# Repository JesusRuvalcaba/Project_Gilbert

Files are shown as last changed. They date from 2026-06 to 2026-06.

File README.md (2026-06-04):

# SHPE - Project Gilbert - Team 2



To control RC Car with cellphone:

1) search for wifi SSID RC-Car
2) enter password: 12345678
3) open up the link below

http://192.168.4.1/

## Project Description

Project Gilbert is a multidisciplinary RC car engineering project developed through SHPE to provide students with practical experience in mechanical, electrical, and manufacturing system design. The project focused on the development and integration of key vehicle subsystems including the rack and pinion steering mechanism, rear suspension system, circuit design, and overall system assembly. Team members collaborated to design, manufacture, assemble, and test a functional RC vehicle while applying engineering concepts learned in coursework to a real-world project environment.

The project also served as a mentorship-driven learning experience where upperclassmen and project leads guided lowerclassmen students throughout the design and development process. Through subsystem integration, design reviews, troubleshooting, and collaborative problem solving, members gained hands-on experience in engineering workflow, manufacturing processes, project coordination, and technical communication.

# Contributors

## Project Leadership Team

This team was responsible for overseeing system integration, project coordination, manufacturing operations, and final project execution.

| Name | Major / Position | Year | Role / Responsibility |
| --- | --- | --- | --- |
| Crystal Duran | SHPE Internal Vice President  | Junior | Project Manager |
| Jesus Ruvalcaba | Electrical Engineering | Senior | Systems and Electrical Operations Lead |
| Gabriel Contreras | Manufacturing Engineering | Sophomore | Manufacturing Operations Lead |
| Pedro Perez | Electromechanical Engineering | Senior | Electromechanical Systems Lead |

## Project Members

These members contributed to the mechanical, electrical, and structural development of the RC car project subsystems.

| Name | Major / Position | Year | Role / Responsibility  |
| --- | --- | --- | --- |
| Josue Garcia | Industrial Engineering | Junior | Rack and Pinion System |
| Andy Petrosyan | Electrical Engineering | Junior | Circuit Design |
| Louis Valdez | Business | Freshman  | Rear Suspension |
| Alison Lobato | Mechanical Engineering | Junior | Rear Suspension |
| David Calvillo | Computer Engineering | Junior | Circuit Assembly |
| Jesus Ruvalcaba | Electrical Engineering | Senior | Electrical Operations  |
| Gabriel Contreras | Manufacturing Engineering | Sophomore | Manufacturing Engr |
| Pedro Perez | Electromechanical Engr | Senior | Electromechanical Engr |

# Cost Breakdown

| Part Name | Quantity | Cost | Link |
| --- | ---: | -----: | --- |
| HiLetgo ESP32 Development Board (3 Pack) | 1 | $17.99 | [ESP32](https://www.amazon.com/Hosyond-Development-Bluetooth-Microcontroller-ESP-WROOM-32/dp/B0F1MS5S8R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) |
| DC Brushed Motor | 2 | $13.78 | [DC Gear Motor](https://www.amazon.com/AUTOTOOLHOME-Torque-Traxxas-Wheels-Electric/dp/B01M58POHF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) |
| L298N Dual H-Bridge Motor Driver | 1 | $13.96 | [L298N Motor Driver](https://www.amazon.com/WWZMDiB-L298N-H-Bridge-Controller-Raspberry/dp/B0CR6BX5QL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) |
| SPST Switch | 1 | $6.39 | [Switch](https://www.amazon.com/DaierTek-Listed-Switches-Automotive-KCD1-5Pack/dp/B07S1MV462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) |
| OVONIC 3S Lipo Battery | 1 | $31.77 | [3S LiPo Battery](https://www.amazon.com/2200mAh-Connector-Airplane-Quadcopter-Helicopter/dp/B09H4KXMQN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) |
| Servo Motor | 1 | $6.99  | [SG90 Servo Motor](amazon.com/WWZMDiB-SG90-Control-Servos-Arduino/dp/B0BKPL2Y21/ref=sr_1_6?crid=1XDTNJYFWU4KS&dib=eyJ2IjoiMSJ9.wV3YRE0vrk5NgH4crAjzDEoYHpGjwiz1Dc3dH15isinuQetsXrt_fsj-g4PERVIjlcI2V5iI2CihxPryMwUoDp31VpTsu_B2qpzuIdXXhYxltGqyU-L95wtvq1BCL1d9exqFyQHK7Nt16iQFr-j1BTByevHCWSGFMXNCUYdxC99eTE45NW--ezeMFAPqfdqIHs2zPiukl7vhPzZloINiAMM8phPkUt_d6b19prHK0awdWFKd6Jh8KGxvOHuXSq5BsIDauRkilJLxKc08cH1Hz7eRctWm45x0yYG4icI7VzE.Q67aCZ9-nO-3GVM6RTWrR4g8cGWnOm49spEnjnQ61W4&dib_tag=se&keywords=servo+motor&qid=1780536184&sprefix=servo+motor%2Caps%2C256&sr=8-6) |
| Adjustable Buck Converter | 1 | $13.99 | [Buck Converter](https://www.amazon.com/Adjustable-Converter-1-25-36v-Efficiency-Regulator/dp/B079N9BFZC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) |
|  Electrical Total Cost (with ~10% tax headroom) | $115.36 |

# Design Review

During the design review, team members presented the current progress of the RC car project to the mentors and project leads, covering the mechanical, electrical, and manufacturing aspects of the system. Discussions included the rack and pinion steering implementation, rear suspension development, circuit design progress, and overall circuit assembly integration. Mentors and leads evaluated subsystem compatibility, reviewed design decisions, and provided technical feedback regarding manufacturability, system reliability, and project organization. The review also focused on identifying integration challenges, validating design approaches, and ensuring each subsystem was progressing according to project objectives and timelines. Action items and recommendations were documented to guide future development and system refinement.
  
https://docs.google.com/presentation/d/1H8Z8eRnMIN4K8d28Y-c5Z4X9QktE7rCTanJxe8Py7WY/edit?usp=sharing

[CDR Gilbert.pdf](https://github.com/user-attachments/files/27575757/CDR.Gilbert.pdf)

# Final Assembly Overview



## Chassis Sub Assembly


## Powertrain Suspension Sub Assembly


## Steering Suspension Sub Assembly


## Future Improvements

One of the main lessons learned from this project was that the drivetrain did not provide enough torque for the vehicle to perform as well as expected, especially when carrying additional load or driving over uneven surfaces. A future version of the design could improve this by using a rear-wheel-drive (RWD) differential system with a 10:1 gear ratio and a single brushless motor paired with an ESC. This setup would provide more torque, improve overall efficiency, and offer better driving performance than the current brushed motor configuration.

Another lesson learned was related to the L298N motor driver. During testing, the driver became noticeably hot when the motors stalled or were placed under heavy load. This occurred because the L298N is based on BJT transistor technology, which is less efficient and dissipates more power as heat compared to modern MOSFET-based motor controllers. Future designs would benefit from using a more efficient motor driver or ESC to reduce heat generation and improve overall system reliability.

Another improvement would be replacing the current phone-based Wi-Fi control system with ESP-NOW communication between two ESP32 modules. During testing, Wi-Fi control through a web page introduced connection delays and depended on a phone being connected to the vehicle's network. Using ESP-NOW would provide a more responsive and reliable control link, creating a driving experience that is closer to a traditional RC vehicle while simplifying operation for the user.

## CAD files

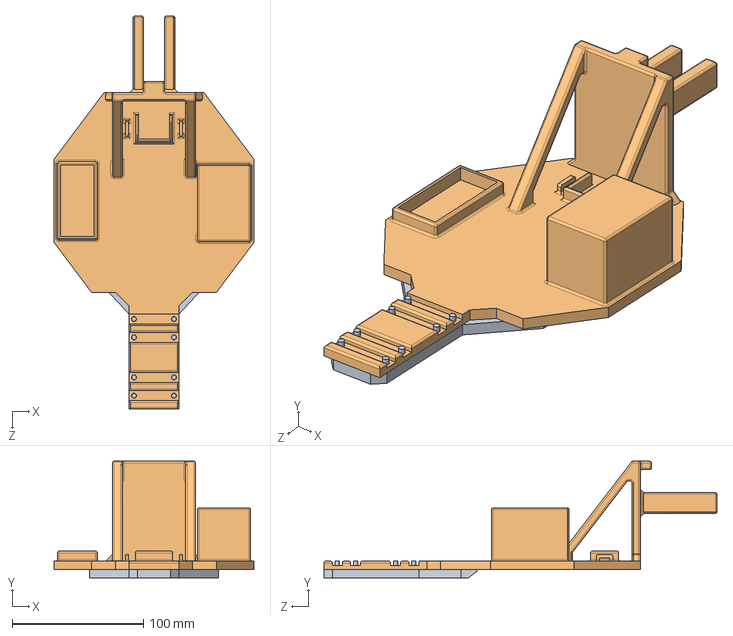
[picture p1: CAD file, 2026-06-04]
RC Project Github/Chassis Sub Assembly/Chassis Sub Assembly.SLDASM
152.4 x 88.9 x 299.7 mm
RC front chassis part
strength plate

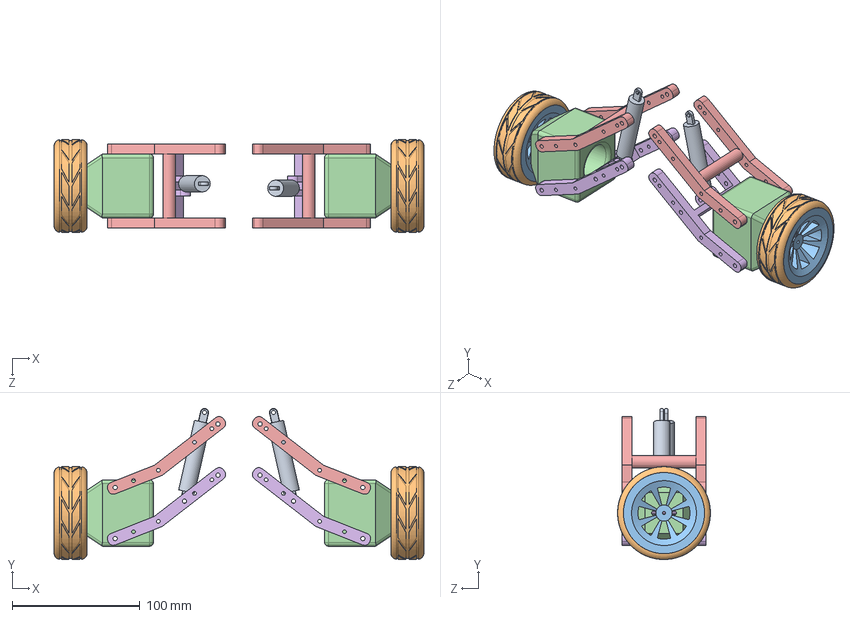
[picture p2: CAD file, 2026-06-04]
RC Project Github/Powertrain Suspension Sub Assembly/Powertrain Suspension Sub Assembly.SLDASM
289.6 x 118.2 x 72.7 mm
Lower Arm to Bracket x 2
Arm to Bracket x 2
Motor Bracket 2 x 2
RC drivetrain rims x 2
RC tire large x 2
RC rear shock x 2

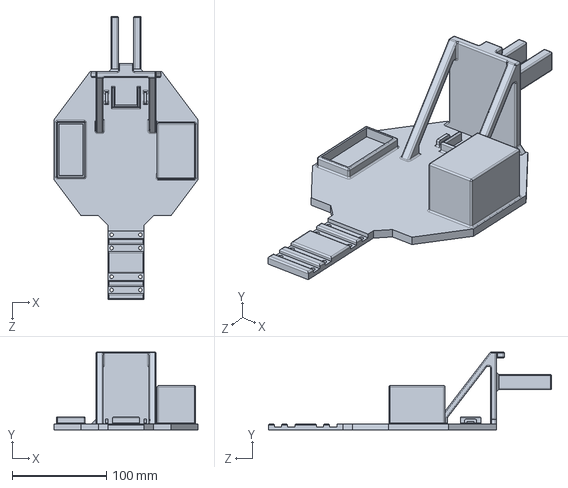
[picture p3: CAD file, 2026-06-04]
RC Project Github/Chassis Sub Assembly/RC front chassis part.SLDPRT
152.4 x 82.5 x 299.7 mm

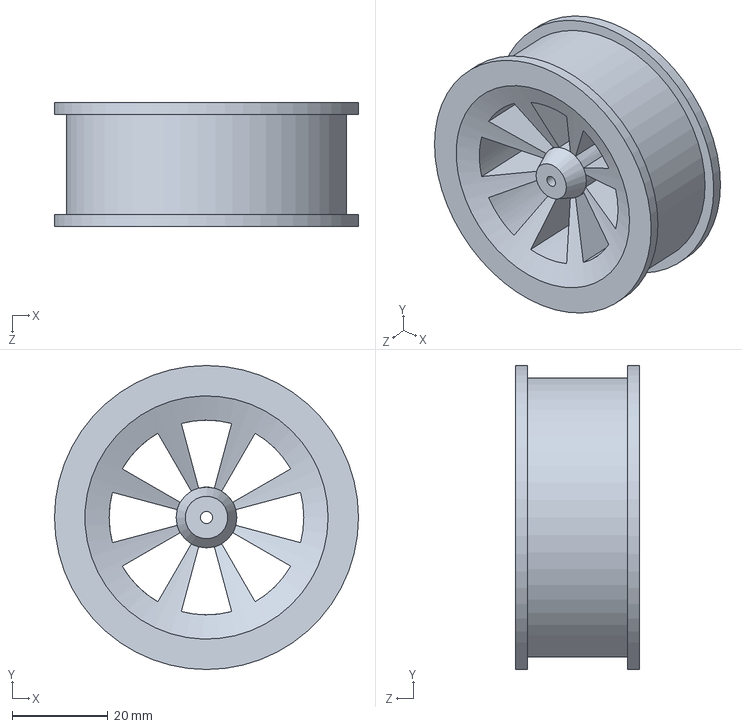
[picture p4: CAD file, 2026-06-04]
RC Project Github/Powertrain Suspension Sub Assembly/RC drivetrain rims.SLDPRT
63.5 x 63.5 x 26.0 mm

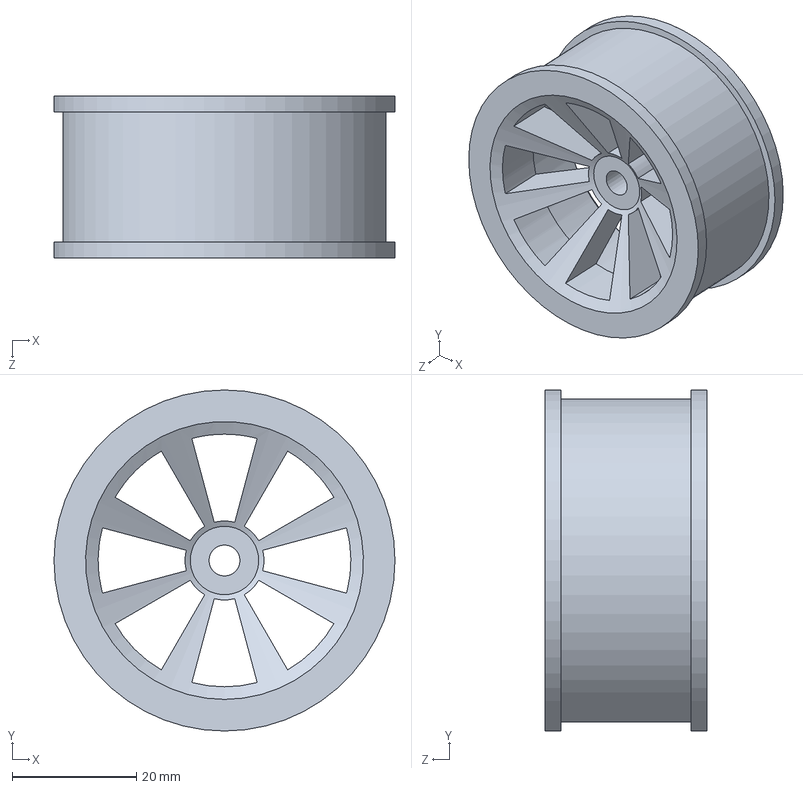
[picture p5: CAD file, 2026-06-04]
RC Project Github/Steering Suspension Sub Assembly/RC Steering rims.SLDPRT
54.9 x 54.9 x 26.0 mm

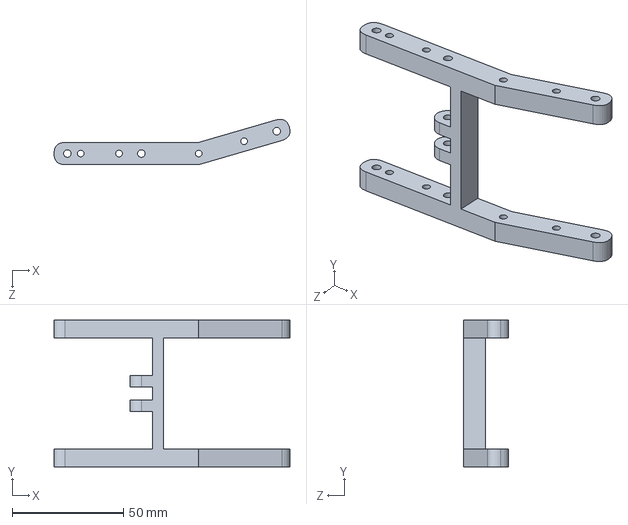
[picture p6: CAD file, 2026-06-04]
RC Project Github/Powertrain Suspension Sub Assembly/Lower Arm to Bracket.SLDPRT
106.0 x 66.0 x 20.4 mm

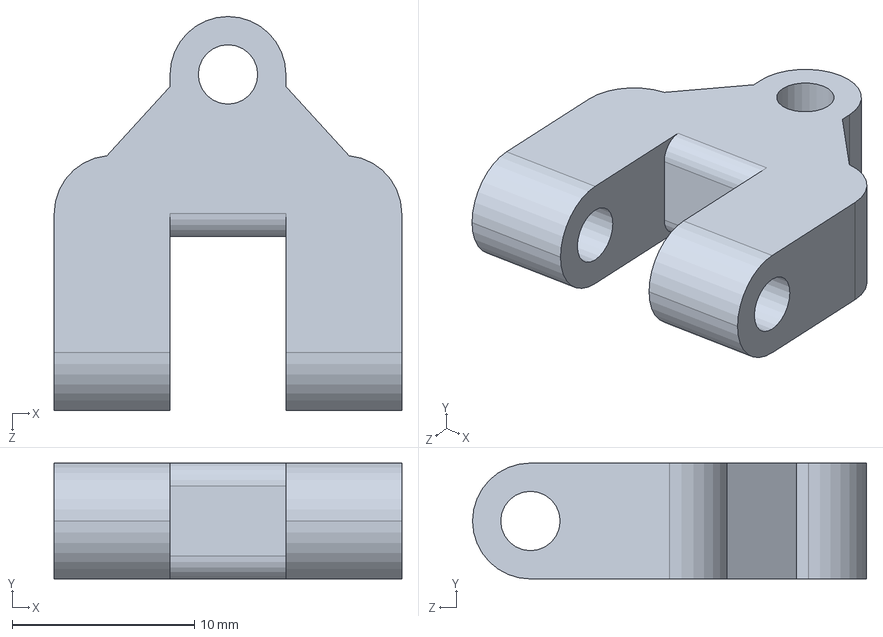
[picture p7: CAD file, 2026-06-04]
RC Project Github/Steering Suspension Sub Assembly/RC Suspension adapter steering linkage.SLDPRT
19.1 x 6.35 x 21.6 mm

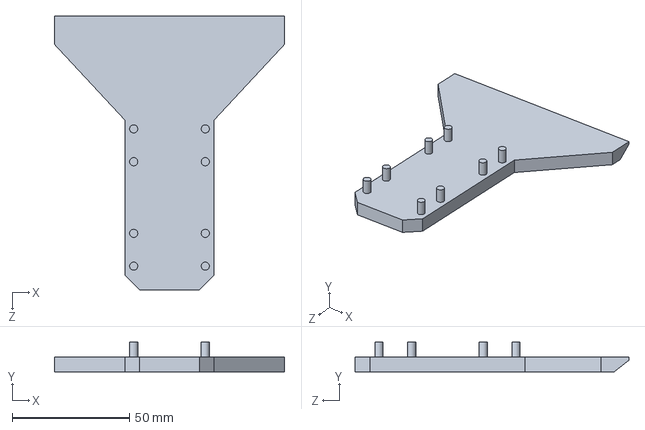
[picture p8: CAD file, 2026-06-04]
RC Project Github/Chassis Sub Assembly/strength plate.SLDPRT
98.1 x 12.7 x 116.6 mm

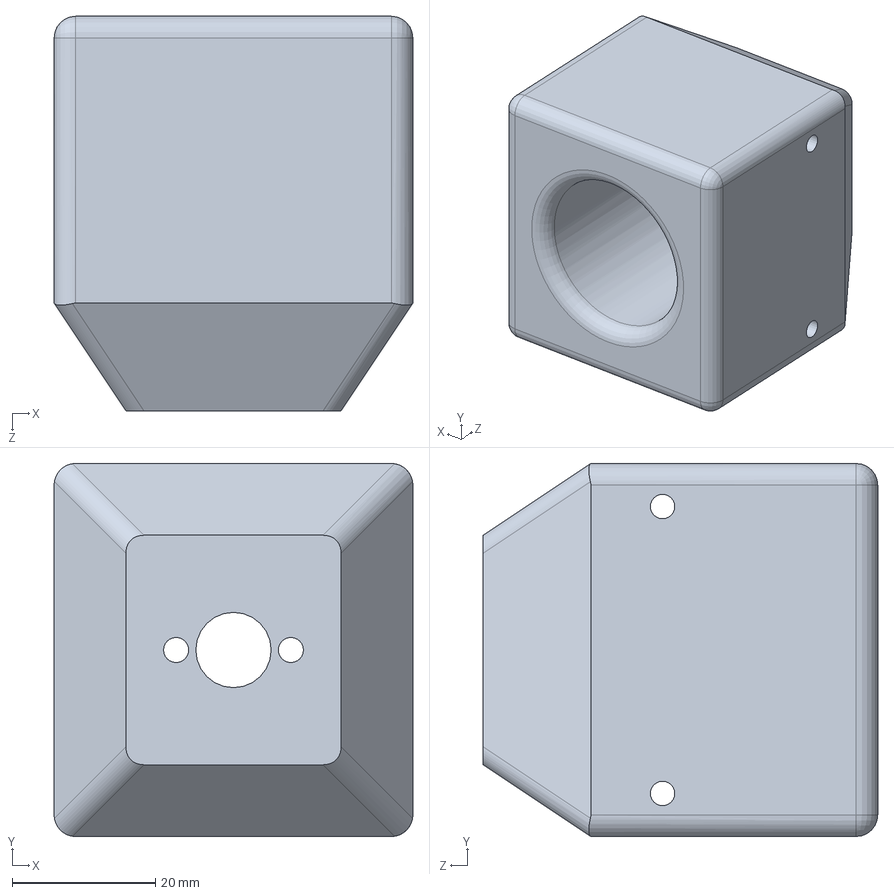
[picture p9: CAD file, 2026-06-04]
RC Project Github/Powertrain Suspension Sub Assembly/Motor Bracket 2.SLDPRT
50.0 x 52.0 x 55.0 mm

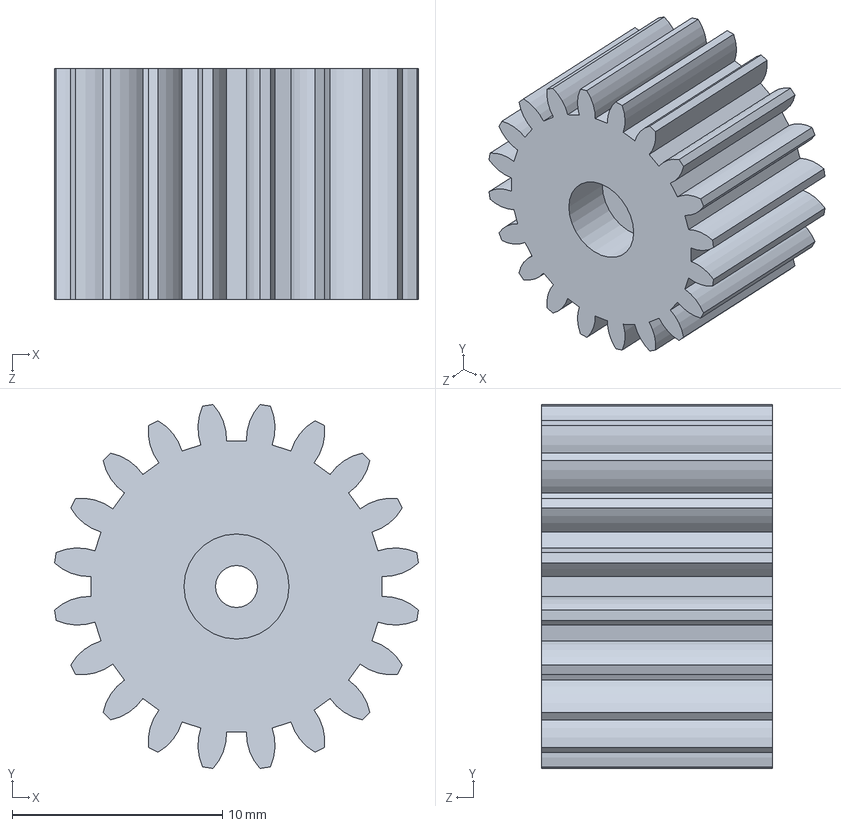
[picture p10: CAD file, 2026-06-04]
RC Project Github/Steering Suspension Sub Assembly/Pinion1 (1).SLDPRT
17.3 x 17.3 x 11.0 mm

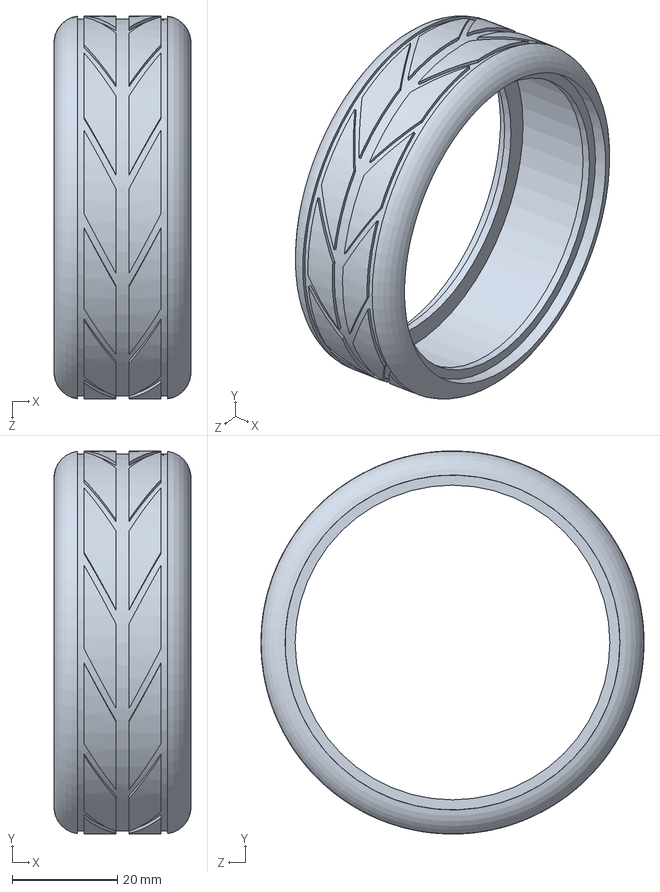
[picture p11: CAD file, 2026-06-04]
RC Project Github/Powertrain Suspension Sub Assembly/RC tire large.SLDPRT
26.0 x 72.7 x 72.7 mm

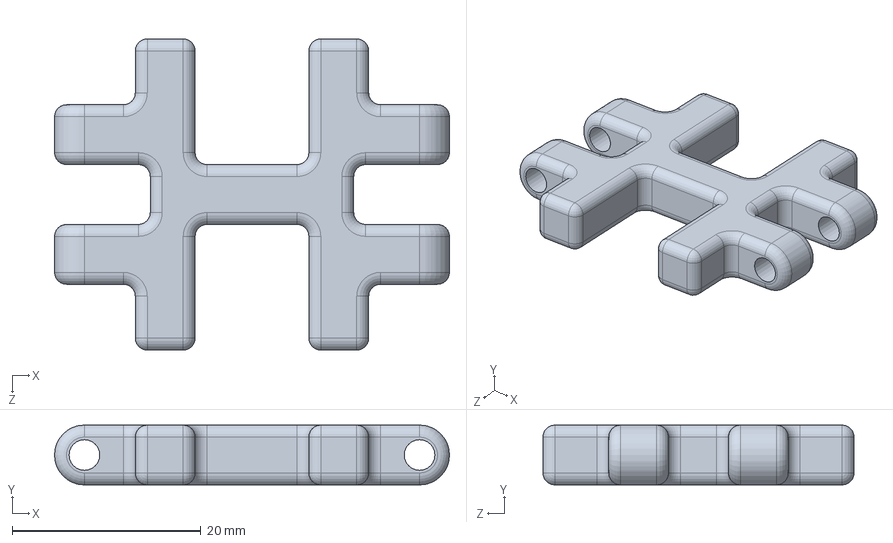
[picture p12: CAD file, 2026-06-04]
RC Project Github/Steering Suspension Sub Assembly/RC personal shock mount insert.SLDPRT
41.9 x 6.35 x 33.0 mm

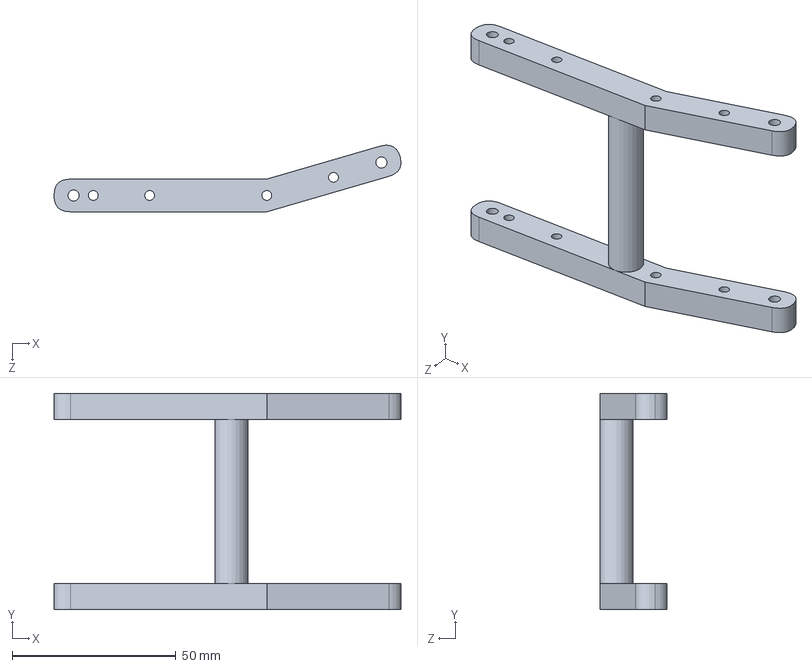
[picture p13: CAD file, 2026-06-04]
RC Project Github/Powertrain Suspension Sub Assembly/Arm to Bracket.SLDPRT
106.0 x 66.0 x 20.4 mm

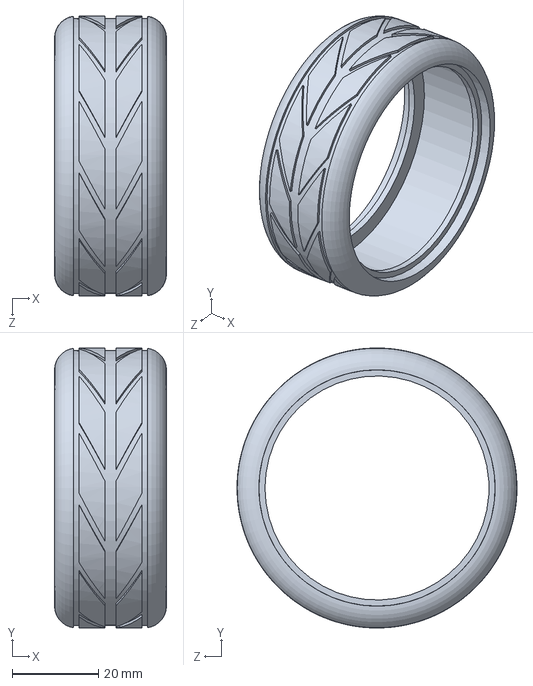
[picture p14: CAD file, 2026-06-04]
RC Project Github/Steering Suspension Sub Assembly/RC tire.SLDPRT
26.0 x 65.0 x 65.0 mm

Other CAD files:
RC Project Github/Full Assembly.SLDASM
RC Project Github/Steering Suspension Sub Assembly/Steering Suspension Sub Assembly.SLDASM
RC Project Github/Powertrain Suspension Sub Assembly/RC rear shock.SLDPRT
RC Project Github/Steering Suspension Sub Assembly/Rack_Pinion.SLDPRT
RC Project Github/Powertrain Suspension Sub Assembly/U bracket new.SLDPRT
RC Project Github/Steering Suspension Sub Assembly/RC bearing wheel mount.SLDPRT
RC Project Github/Steering Suspension Sub Assembly/RC shock.SLDPRT
RC Project Github/Steering Suspension Sub Assembly/RC suspension arm and shock mount.SLDPRT
RC Project Github/Steering Suspension Sub Assembly/RC suspension arm mount rack plus servo.SLDPRT
RC Project Github/Steering Suspension Sub Assembly/RC suspension arm mount.SLDPRT
RC Project Github/Steering Suspension Sub Assembly/RC suspension arm.SLDPRT
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

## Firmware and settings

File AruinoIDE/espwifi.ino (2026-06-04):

#include <WiFi.h>
#include <WebServer.h>
#include <WebSocketsServer.h>
#include <ESP32Servo.h>

// -------------------- ACCESS POINT --------------------
const char* ssid     = "ESP32-RC";
const char* password = "12345678";

// -------------------- WEB SERVER & WEBSOCKET --------------------
WebServer server(80);
WebSocketsServer webSocket(81);

// -------------------- L298N MOTOR PINS --------------------
// Motor A
const int ENA = 25;   // PWM speed
const int IN1 = 26;   // Direction
const int IN2 = 27;   // Direction

// Motor B
const int ENB = 14;   // PWM speed
const int IN3 = 32;   // Direction
const int IN4 = 33;   // Direction

// -------------------- SERVO --------------------
Servo steering;
const int servoPin = 18;

// -------------------- CONTROL VARIABLES --------------------
int throttleValue = 0;
int steeringValue = 90;

// -------------------- MOTOR CONTROL --------------------
void driveMotors(int speed) {
  speed = constrain(speed, -255, 255);

  Serial.print("Motor command: ");
  Serial.println(speed);

  int pwmVal = abs(speed);

  if (speed > 0) {
    // Forward
    digitalWrite(IN1, HIGH);
    digitalWrite(IN2, LOW);

    digitalWrite(IN3, HIGH);
    digitalWrite(IN4, LOW);

    ledcWrite(ENA, pwmVal);
    ledcWrite(ENB, pwmVal);
  } 
  else if (speed < 0) {
    // Reverse
    digitalWrite(IN1, LOW);
    digitalWrite(IN2, HIGH);

    digitalWrite(IN3, LOW);
    digitalWrite(IN4, HIGH);

    ledcWrite(ENA, pwmVal);
    ledcWrite(ENB, pwmVal);
  } 
  else {
    // Stop
    digitalWrite(IN1, LOW);
    digitalWrite(IN2, LOW);

    digitalWrite(IN3, LOW);
    digitalWrite(IN4, LOW);

    ledcWrite(ENA, 0);
    ledcWrite(ENB, 0);
  }
}

// -------------------- WEBSOCKET EVENT --------------------
void webSocketEvent(uint8_t num, WStype_t type, uint8_t* payload, size_t length) {
  if (type == WStype_TEXT) {
    String msg = String((char*)payload);

    Serial.print("WS received: ");
    Serial.println(msg);

    if (msg.startsWith("T:")) {
      throttleValue = constrain(msg.substring(2).toInt(), -255, 255);
      driveMotors(throttleValue);
    } 
    else if (msg.startsWith("S:")) {
      steeringValue = constrain(msg.substring(2).toInt(), 0, 180);
      steering.write(steeringValue);

      Serial.print("Steer command: ");
      Serial.println(steeringValue);
    }
  } 
  else if (type == WStype_DISCONNECTED) {
    Serial.println("Client disconnected - stopping motors");
    driveMotors(0);
  }
}

// -------------------- WEBPAGE HTML --------------------
String webpage = R"rawliteral(
<!DOCTYPE html>
<html>
<head>
<meta name="viewport" content="width=device-width, initial-scale=1">
<title>ESP32 RC Car</title>
<style>
  body {
    font-family: Arial, sans-serif;
    text-align: center;
    background: #111;
    color: #fff;
    padding: 20px;
  }

  h1 {
    color: #0f0;
  }

  .label {
    font-size: 1.1em;
    margin: 24px 0 8px;
  }

  #status {
    font-size: 0.8em;
    color: #f80;
    margin-bottom: 16px;
  }

  input[type=range] {
    -webkit-appearance: none;
    appearance: none;
    width: 75%;
    height: 28px;
    background: #333;
    border-radius: 14px;
    outline: none;
    cursor: pointer;
  }

  input[type=range]::-webkit-slider-thumb {
    -webkit-appearance: none;
    appearance: none;
    width: 44px;
    height: 44px;
    border-radius: 50%;
    background: #0f0;
    cursor: pointer;
    box-shadow: 0 0 6px #0f0;
  }

  input[type=range]::-moz-range-thumb {
    width: 44px;
    height: 44px;
    border-radius: 50%;
    background: #0f0;
    cursor: pointer;
    box-shadow: 0 0 6px #0f0;
    border: none;
  }

  #throttleVal, #steerVal {
    font-size: 1.3em;
    font-weight: bold;
    margin-top: 6px;
    color: #0f0;
  }
</style>
</head>
<body>

<h1>ESP32 RC Car</h1>
<div id="status">Connecting...</div>

<div class="label">Steering Servo</div>
<input type="range" min="0" max="180" value="90" id="steerSlider"
  oninput="sendSteer(this.value)">
<div id="steerVal">90°</div>

<div class="label">Throttle Motors</div>
<input type="range" min="-255" max="255" value="0" id="throttleSlider"
  oninput="sendThrottle(this.value)"
  onpointerup="resetThrottle()"
  ontouchend="resetThrottle()">
<div id="throttleVal">0</div>

<script>
  var ws;

  function connect() {
    ws = new WebSocket('ws://' + location.hostname + ':81/');

    ws.onopen = function() {
      document.getElementById('status').textContent = 'Connected';
      document.getElementById('status').style.color = '#0f0';
      ws.send('T:0');
    };

    ws.onclose = function() {
      document.getElementById('status').textContent = 'Disconnected - reconnecting...';
      document.getElementById('status').style.color = '#f80';
      document.getElementById('throttleSlider').value = 0;
      document.getElementById('throttleVal').textContent = '0';
      setTimeout(connect, 2000);
    };

    ws.onerror = function() {
      ws.close();
    };
  }

  function sendSteer(v) {
    document.getElementById('steerVal').textContent = v + '°';

    if (ws && ws.readyState === WebSocket.OPEN) {
      ws.send('S:' + v);
    }
  }

  function sendThrottle(v) {
    document.getElementById('throttleVal').textContent = v;

    if (ws && ws.readyState === WebSocket.OPEN) {
      ws.send('T:' + v);
    }
  }

  function resetThrottle() {
    document.getElementById('throttleSlider').value = 0;
    sendThrottle(0);
  }

  connect();
</script>

</body>
</html>
)rawliteral";

// -------------------- SETUP --------------------
void setup() {
  Serial.begin(115200);

  // Motor direction pins
  pinMode(IN1, OUTPUT);
  pinMode(IN2, OUTPUT);
  pinMode(IN3, OUTPUT);
  pinMode(IN4, OUTPUT);

  // Start motors stopped
  digitalWrite(IN1, LOW);
  digitalWrite(IN2, LOW);
  digitalWrite(IN3, LOW);
  digitalWrite(IN4, LOW);

  // ESP32 core 3.x PWM setup
  ledcAttach(ENA, 20000, 8);
  ledcAttach(ENB, 20000, 8);

  ledcWrite(ENA, 0);
  ledcWrite(ENB, 0);

  // Servo setup
  ESP32PWM::allocateTimer(2);
  ESP32PWM::allocateTimer(3);

  steering.setPeriodHertz(50);
  steering.attach(servoPin, 500, 2400);
  steering.write(90);

  // WiFi Access Point
  WiFi.softAP(ssid, password);

  Serial.print("AP IP: ");
  Serial.println(WiFi.softAPIP());

  // Web server
  server.on("/", []() {
    server.send(200, "text/html", webpage);
  });

  server.begin();

  // WebSocket
  webSocket.begin();
  webSocket.onEvent(webSocketEvent);

  Serial.println("Ready.");
}

// -------------------- LOOP --------------------
void loop() {
  server.handleClient();
  webSocket.loop();
}
